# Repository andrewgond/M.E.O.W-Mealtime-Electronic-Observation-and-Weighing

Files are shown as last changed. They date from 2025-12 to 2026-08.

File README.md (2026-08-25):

---

# M.E.O.W. — Mealtime Electronic Observation & Weighing (WIP)

**An Open-Source Smart Pet Feeder with Integrated Weight Tracking**
*Senior Design Capstone — Oregon State University*
*Andrew Gondoputro
*Ahmad Alajmi
*Craig Kelley

---

## Project Status: Work in Progress (WIP)

This repository documents the development of the **M.E.O.W. automated pet feeder**, a system that dispenses food and logs pet weight using load cells and RFID identification. The goal is to support long-term tracking of pet health trends such as obesity, malnutrition, or abnormal feeding behavior.

---

# Overview

The M.E.O.W. system is designed to:

* Run on standard wall power
* Measure pet weight within ±20 grams
* Dispense food within ±60 grams
* Log food and weight data within 10 seconds
* Store at least 10 days of logs
* Support up to 4 pets via RFID
* Allow user-configurable feeding parameters

Unlike typical auto-feeders, M.E.O.W. integrates *health-relevant data logging* for improved wellness monitoring.

---

# DEI Commitment

The project emphasizes accessibility, inclusion, and open-source availability.
The system aims to be easy to use for any pet owner, with a simple UI and customizable configuration.

---

# System Architecture

## Top-Level Summary

The system is divided into modular subsystems:

* Power Distribution
* Enclosure & Kinematics
* Sensors
* Code & Database Storage
* Microcontroller (ESP32)
* UI + Web App

---

# 🔌 Block Diagram (Placeholder)

```
[ Block Diagram Placeholder — MEOW System ]
```

```
[ System-Level Diagram Placeholder — Showing Subsystem Connections ]
```

---

# 🔧 Subsystem Descriptions

### 1. Power Distribution

Converts AC wall power into stable low-voltage DC rails for sensors, logic, and actuators.

### 2. Enclosure & Kinematics

Includes the physical enclosure, motors, dispensing components, and protective mechanical structures.

### 3. Sensors

* Load cells to capture weight
* RFID reader for pet identification

### 4. Code & Database

MicroSD-based data storage for logs, timestamps, food dispensing events, and per-pet data.

### 5. Microcontroller

ESP32 manages sensors, actuator control, data logging, and UI communication.

### 6. UI + Web App

Browser-based dashboard for monitoring weight trends, adjusting feeding schedules, and visualizing logs.

---

# Interface Definitions

| Interface | Description |
| --- | --- |
| AC_pwr_in | Wall power input |
| DC_pwr_in_5v | Regulated 5V power rail |
| env_weight | Load cell weight signal |
| env_rfid_dist | RFID read distance |
| if_user_commands_in | User command interface |
| motor_ctrl_out | Motor control signals |
| ui_disp_ui | Display output |
| db_data_out | Data sent from database |
| db_data_to_ui | Data sent from microcontroller to UI |

---

# Verification Framework

Each subsystem will include:

* Interface validation
* General validation
* Verification steps
* References
* Success criteria

Example tasks include:

* Maximum current draw calculations
* Logic level matching (ESP32 ↔ SD card)
* Regulator thermal margins
* Sensor precision/accuracy tests

---

# References

A `/docs/references.md` file will be added containing:

* Component datasheets
* Industry standards
* Research sources for pet feeding and behavior
* Market analysis references

---

# Future Work

### Technical Recommendations (WIP)

* Improve sensor calibration algorithms
* Add multi-pet discrimination logic
* Enhance UI accessibility
* Expand SD logging features
* Improve enclosure materials

### Teamwork/Communication Recommendations

* Better task delegation strategy
* Implement weekly fixed-scope sprints

---

# Project Roadmap

### Phase 1 — Hardware Bring-Up

* [ ] Power subsystem validation
* [ ] Load cell calibration
* [ ] Servo/stepper testing
* [ ] RFID module bring-up

### Phase 2 — Firmware

* [ ] Sensor polling loops
* [ ] SD logging system
* [ ] Motor control logic
* [ ] Error handling

### Phase 3 — UI + Data

* [ ] Web dashboard
* [ ] Trend graphs
* [ ] Pet profiles

### Phase 4 — Final Integration

* [ ] Full hardware + firmware integration
* [ ] Enclosure finalization
* [ ] Stress testing
* [ ] Final documentation

---

# Contact

Project Contributors:

* Ahmad Alajmi
* Andrew Gondoputro
* Craig Kelley

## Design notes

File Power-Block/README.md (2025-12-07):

#1.1. Power Block - Andrew Gondoputro

This block is located on the exterior input of the system, accepting standard U.S. wall power and converting it into a regulated low-voltage DC bus at several predetermined voltages that all other M.E.O.W. subsystems can utilize. Every other block in the system depends on this stable power for its parts to function and is in charge of isolation, overcurrent protection, and providing enough power for the other components in the system.

#1.1.1. Description

The Power Distribution Block takes the AC_pwr_in interface with the US Standard 120 VAC, 60 Hz from a U.S. wall outlet. This allows us to plug into a wall and have a consistent power source, unlike a battery. Internally, the block then takes this AC wall power and turns it into a 12V rail, for higher voltage operations on the system like the kinematics of moving the stepper motors. It then uses that 12V rail to step down into both a 5V rail and a 3.3V rail, used for lower voltage components like the microcontroller, stepper drivers and sensors.

#1.1.2. Design

The design of the power station first starts with connecting to a wall outlet. Standard NEMA US Connectors consist of two pinned enclosures. We decided to have the cleanest AC->DC conversion to use a purchasable wall mount 12V 2A adapter with a barrel jack connector [10]. This also allows the cable of our overall system to be modular in which you can disconnect from the system and also easily replace.

Starting our circuit, we designed a barrel jack connector as an input for just a power and gnd, making sure that the footprint was right on the schematic. From the power pin A we put a Schmitt trigger diode so we would not get any accidental reverse current. The next node from the diode would just be used as the 12 V rail for the system since it was already cleaned by the adapter.

We decided to use two-buck conversions for the least amount of heat problems. We went with the LM2596S because of its easy accessibility of purchasing and consistent documentation and usages. The system then uses a 470uF and 1uF capacitor to deal with any low/high frequency noise. Our system uses two LM2596S taking the 12V input, with one LM2596S downstepping to 5V and the other downstepping to 3.3V. Following the example of [3, pg 1] we looked for capacitors and inductors and the wiring of the buck converters. Tables 9.1 and 9.3 [3, pg 21] showed us which inductors and capacitors to use. Which can be seen in our schematic [Figure 3.1.1]. The outputs of the buck converters gave us our rails we would be using.

Moving onto our PCB we that we decided that our project would later become open source, we tried to use a lot of through-hole components for easier assembly. We spent a long time looking for footprints and then making 1.5mm traces for high-power components. The pcb layout ended up being about the size of a credit card and can be seen in Figure 3.1.2. We then used screw terminals for the outputs of the rails for testing purposes when creating the PCB.

#Design Artifacts

Figure 3.1.1 KiCAD Schematic
Figure 3.1.2 KiCAD PCB Trace Schematic
Figure 3.1.2 KiCAD PCB 3D Model

#1.1.3. General Validation

It uses an AC to DC 12V power adapter to get the first regulated rail. It then uses a DC Voltage regulator to convert that 12V DC to a single 5 V DC regulated output that is used by the other blocks. Internally, this 5V is then fed into another voltage regulator to get a single 3.3 V DC regulated output for a microcontroller. This design aligns with the top-level system plan, which calls out a dedicated power block alongside enclosure/kinematics, sensors, microcontroller, code/database, and UI.

#1.1.4. Interface Validation

Interface property
Be sure to use the naming convention “from_to_type” here.
Why is this interface property this value?
How do you know your design details will meet or exceed this property? Cite your sources in IEEE.

**Interface 1: ext_power_acpwr**
| Interface property | Why is this interface property this value? | How do you know your design details will meet or exceed this property? |
| --- | --- | --- |
| **V_rms = 120 VAC @ 60 Hz (wall_pwr_pwr_ac)** | Section 1 and 2 say “The system will use standard US wall.” U.S. residential mains are 120 VAC nominal at 60 Hz. | The selected AC-DC module is rated for 90–132 VAC input at 47–63 Hz, so 120 VAC/60 Hz is inside range. [10] |
| **I_in_max ≤ 0.5 A (wall_pwr_pwr_ac)** | A 15 W / 5 V / 3 A supply at 120 VAC draws ~0.17 A even at poor PF. | Adapter rating guarantees operation below this current. [10] |
| **Connector = 2-pin shielded / enclosure mounted** | Since we take wall power, this is the easiest AC→DC form factor. | Using an IEC/2-pin inlet with strain relief meets electrical and mechanical requirements; it is also the purchased part. |
| **Barrel Connector Between PCB and Outlet** | Typical devices use a separate connector so the cord is removable. | 2.1 mm male/female barrel jacks are used. [10] |

**Interface 2. power_enc_dcpwr12v**
| Interface property | Why is this interface property this value? | How do you know your design meets this property? |
| --- | --- | --- |
| **V_min = 11.1 V (pwr_all_dcpwr)** | 12 V ±7.5% allows the buck converter and stepper motors to operate correctly. | Stepper motor is rated 8–35 V, well within range. [7] |
| **V_max = 12.9 V (pwr_all_dcpwr)** | Same tolerance requirement as above. | Stepper motor and converters operate fully across this range. [7] |
| **I_nom = 250 mA** | Expected slow-movement draw of the motor. | LM2596S converter maintains regulation at no load and normal load. [3] |
| **I_peak = 300 mA** | Ensures startup + acceleration overhead is supported. | Stepper motors typically require ≤ 300 mA under these operating conditions. [7] |

**Interface 3. dc_pwr_out_5v**

| Interface property | Why is this interface property this value? | How do you know your design meets/exceeds it? |
| --- | --- | --- |
| **V_min = 4.625 V** | 5 V −7.5% is USB and logic lower tolerance limit. | LM2596S guarantees ±10% output; verified by open-circuit tests. [3] |
| **V_max = 5.375 V** | 5 V +7.5% keeps downstream devices safe. | LM2596S ±5% accuracy meets this requirement. |
| **I_nominal = 100 mA** | Matches typical load cells and sensor current requirements. | ESP32 quiescent current = 5 mA; total expected load = 105 mA < nominal limit. [2][6] |
| **I_peak = 300 mA** | Supports transient demands. | Load remains below converter limit; ESP32 remains far under this threshold. |

Interface 4. dc_pwr_out_3.3v
| Interface property | Why is this interface property this value? | How do you know your design meets/exceeds it? |
| --- | --- | --- |
| **V_min = 3.0525 V** | 3.3 V −7.5% meets logic tolerance for ESP32/sensors. | LM2596S regulation ensures output stays above this even under load. |
| **V_max = 3.5475 V** | 3.3 V +7.5% stays within max voltage for logic chips. | Verified by open-circuit measurement ≤ 3.465 V. [3] |
| **I_nominal = 100 mA ± 25 mA** | Normal operating range for microcontroller + peripherals. | ESP32 quiescent is 5 mA; typical load ≤ 105 mA. |
| **I_peak = 300 mA** | Allows for transient inrush conditions. | Remains well below LM2596S converter limits. |

#1.1.5. Verification Process
Interface 1: ext_power_acpwr

Barrel Jack Connector and 2-pin shielded connector

Connect the cable to the system’s PCB barrel jack connector

Plug the system’s wall connector into the wall
VRMS (NEMA Standard) and Iinmax (Wall Adapter)

Use a multimeter on the rails to check the voltage of each rail receiving their expected values

Fully verify the interfaces 2-4 validation’s to ensure its working'

Interface 2: power_enc_dcpwr12v

11.1V < Vout < 12.9V and Imin= 0 (Verifying when motor off)

Disconnect any loads on the 12V rail

While the system is connected to wall power, use a multimeter to verify that the values are within the range

11.4V < Vout < 12.6V when Imax= 250 mA (Verifying when motor on)
3. Have the system disconnected from the wall
4. Put the electronic load on the 12V rail with power and gnd properly wired
a. Set the load to I = 0.3 and then turn it on
b. Put a resistor value of 22 ohms on the 5V Rail (Simulating I = 227mA)
c. resistor value of 22 ohms on the 3V Rail (Simulating I = 150mA)
5. Plug the system into the wall
6. Check the electronic load to see the actual current and the voltage across the node to verify its within the values

11.4V < Vout < 12.6V when Imax = 300 mA (Verifying under max load range)

Unplug the system

Change electronic load to I=0.3

Plug the system back into the wall

Check the electronic load to see the actual current and the voltage across the node to verify its within the values

Interface 3: power_sensors_dcpwr5v

4.625 V < Vout < 5.375 V
5. Disconnect any loads on the 5V rail
6. While the system is connected to wall power, use a multimeter to verify that the values are within the range

4.625 V < Vout < 5.375 V when Inom = 200 mA (Verifying under nominal load range)
7. Have the system disconnected from the wall
8. Put the electronic load on the 12V rail with power and gnd properly wired
a. Set the load to I = 0.1 and then turn it on
b. Put a resistor value of 47 ohms on the 12V Rail (Simulating I = 255mA)
c. resistor value of 22 ohms on the 3V Rail (Simulating I = 150mA)
9. Plug the system into the wall
10. Check the electronic load to see the actual current and the voltage across the node to verify its within the values

4.625 V < Vout < 5.375 V when Imax = 300 mA (Verifying under max load range)
11. Unplug the system
12. Change electronic load to I=0.3
13. Plug the system back into the wall
14. Check the electronic load to see the actual current and the voltage across the node to verify its within the values

Interface 4: power_enc_dcpwr3.3v

3.05 V < Vout < 3.55 V (Verifying when system idle)

Disconnect any loads on the 12V rail

While the system is connected to wall power, use a multimeter to verify that the values are within the range

3.05 V < Vout < 3.55 V when Inom = 200 mA (Verifying under nominal load range)
3. Have the system disconnected from the wall
4. Put the electronic load on the 12V rail with power and gnd properly wired
a. Set the load to I = 0.1 and then turn it on
b. Put a resistor value of 47 ohms on the 12V Rail (Simulating I = 255mA)
c. resistor value of 22 ohms on the 5V Rail (Simulating I = 227mA)
5. Plug the system into the wall
6. Check the electronic load to see the actual current and the voltage across the node to verify its within the values

3.05 V < Vout < 3.55 V when Imax = 300 mA (Verifying under max load range)
7. Unplug the system
8. Change electronic load to I=0.3
9. Plug the system back into the wall
10. Check the electronic load to see the actual current and the voltage across the node to verify its within the values

1.1.6. References

(All references preserved exactly from the PDF)

[1] Americord Custom Power Cords, “NEMA Chart: Know Your Plug And Receptacle,” Americord Blog, Jul. 24, 2021.
[2] ON Semiconductor, “NCP1117/D: 1.0 A Low-Dropout Positive Fixed and Adjustable Voltage Regulators.”
[3] Texas Instruments / LM2596S Evaluation Module, “LM2596S EV Board Datasheet,” Digi-Key, 2020.
[4] Cliff Electronic Components Ltd., “Model No. DC-10A / DC-10B – Part No. FC68148.”
[5] Espressif Systems, “ESP32-WROOM-32 Datasheet.”
[6] SparkFun Electronics, “ESP32 Datasheet (Alternate Copy).”
[7] Allegro MicroSystems, “A4988: Microstepping Motor Driver with Translator.”
[8] Rubycon Corp., “YXJ Series Aluminum Electrolytic Capacitors.”
[9] Rubycon Corp., “ZLH Series Aluminum Electrolytic Capacitors.”
[10] Yageo Group, “12V 2A Power Supply.”
[11] Vishay Semiconductors, “1N5820 Schottky Barrier Rectifier.”
[12] Würth Elektronik, “744731680 – WE-PD Series Shielded Power Inductor.”
[13] Würth Elektronik, “7447471470 – WE-HCI Series High-Current Inductor.”
[14] Texas Instruments, “LM2596: SIMPLE SWITCHER® 150-kHz 3-A Step-Down Voltage Regulator.”

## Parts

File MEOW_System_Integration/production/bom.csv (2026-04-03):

Designator | Footprint | Quantity | Value | LCSC Part #
- 12V +, - 3.3V +, - 5V + | TerminalBlock_TE_282834-2_1x02_P2.54mm_Horizontal | 3 | Terminal Out (Screw)
A1 | Pololu_Breakout-16_15.2x20.3mm | 1 | A4988
C1 | CP_Elec_8x10 | 1 | 470 uF
C2 | 0603 | 1 | 1uF
C3, C4 | CP_Elec_6.3x7.7 | 2 | 220 uF
C5 | 0603 | 1 | 0.1uF
D1, D2, D3 | D_SMA | 3 | 1N5820
J1, J11 | PinHeader_1x04_P2.54mm_Vertical | 2 | Conn_01x04_Pin
J10, J8 | PinHeader_1x19_P2.54mm_Vertical | 2 | Conn_01x19_Pin
J12, J15 | PinSocket_1x02_P2.54mm_Vertical | 2 | Conn_01x02_Pin
J9 | PinSocket_1x04_P2.54mm_Vertical | 1 | Conn_01x04_Pin
JP1 | JST_EH_B2B-EH-A_1x02_P2.50mm_Vertical | 1 | Power Connector
JP2 | JST_EH_B2B-EH-A_1x02_P2.50mm_Vertical | 1 | Power Switch Connector
L1 | L_12x12mm_H4.5mm | 1 | 68 uH
L2 | L_12x12mm_H4.5mm | 1 | 47uH
MCU1 | ESP32_38pin | 1 | ~
R1, R2, R3, R4, R5 | 0603 | 5 | 10kohm
RDM1 | RDM6300 | 1 | RDM6300
S1, S2 | SPARKFUN_SEN-13879 | 2 | SEN-13879
SD1 | MEM20900014500A | 1 | MEM2090-00-145-00-A
U1 | TO-263-5_TabPin3 | 1 | LM2596S-5
U2 | TO-263-5_TabPin3 | 1 | LM2596S-3.3

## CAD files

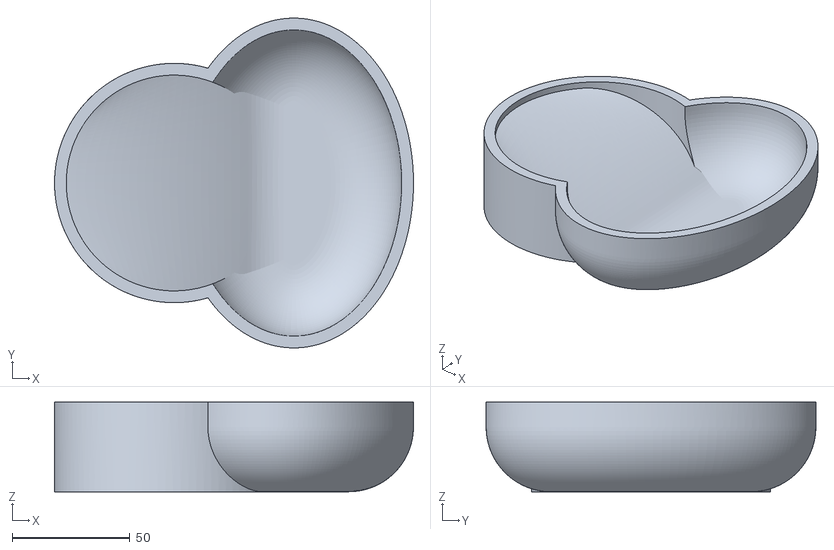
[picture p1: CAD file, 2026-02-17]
Enclosure-Kinematics-Block/3D-Models/EncBowlV1.stl
152.4 x 140.0 x 38.0

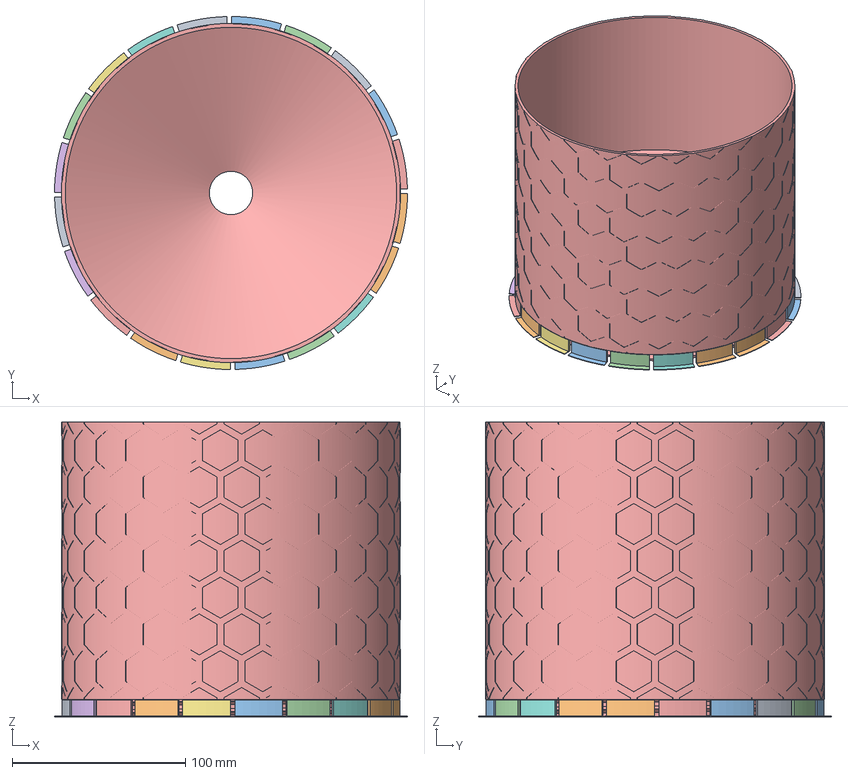
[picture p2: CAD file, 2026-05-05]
EnclosureV2_Print_Models/Top.3mf
203.6 x 203.6 x 170.0 mm

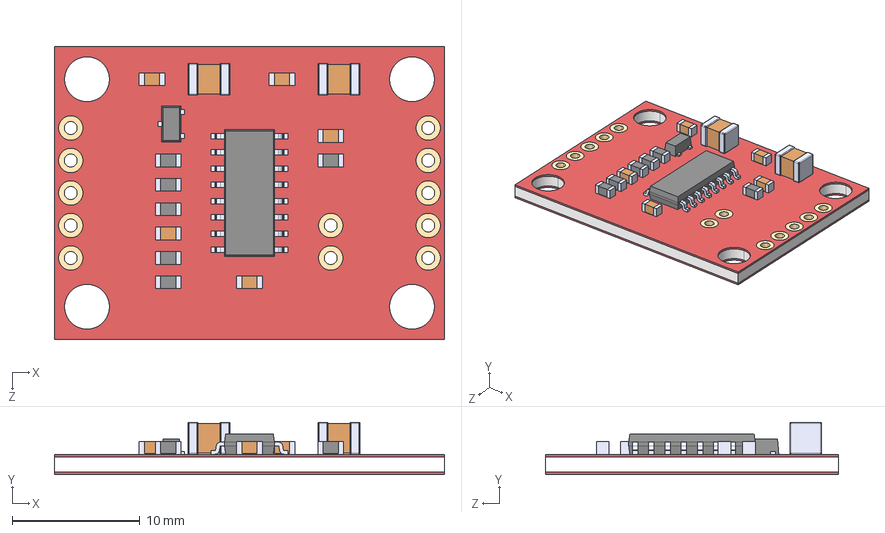
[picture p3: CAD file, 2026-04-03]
Extra Kicad Libraries/KiCAD_Footprints/SEN-13879.step
30.5 x 4.10 x 22.9 mm

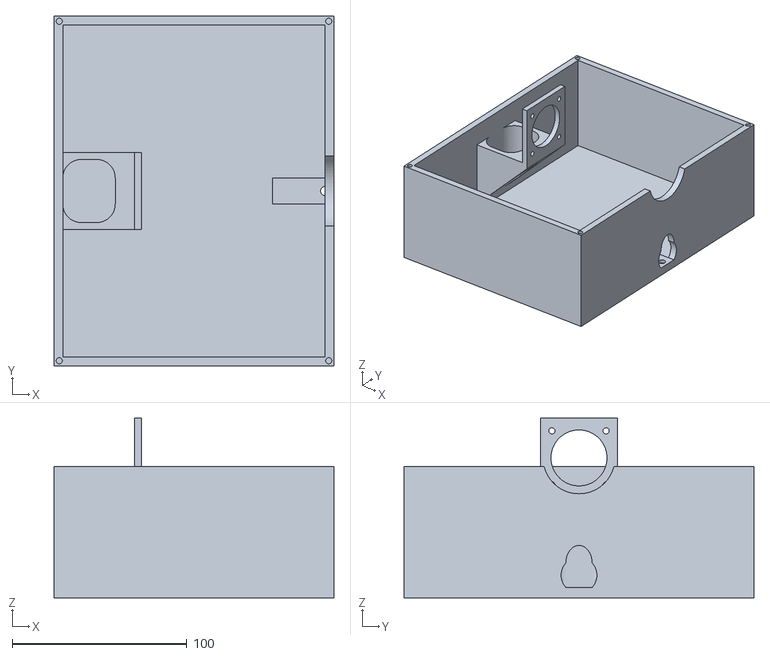
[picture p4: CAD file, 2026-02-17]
Enclosure-Kinematics-Block/3D-Models/EncBotV1.stl
160.0 x 200.0 x 102.8

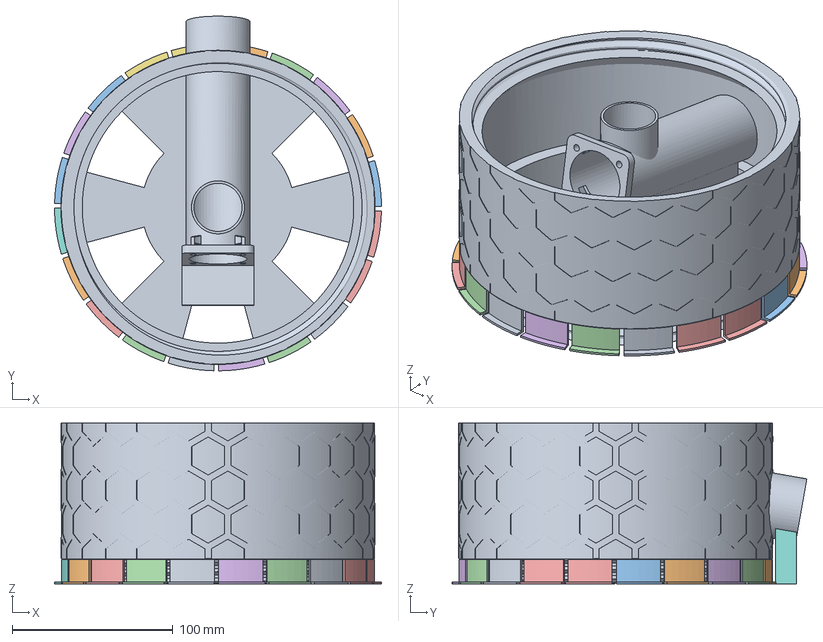
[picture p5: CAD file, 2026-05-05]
EnclosureV2_Print_Models/mid.3mf
203.6 x 220.8 x 100.0 mm

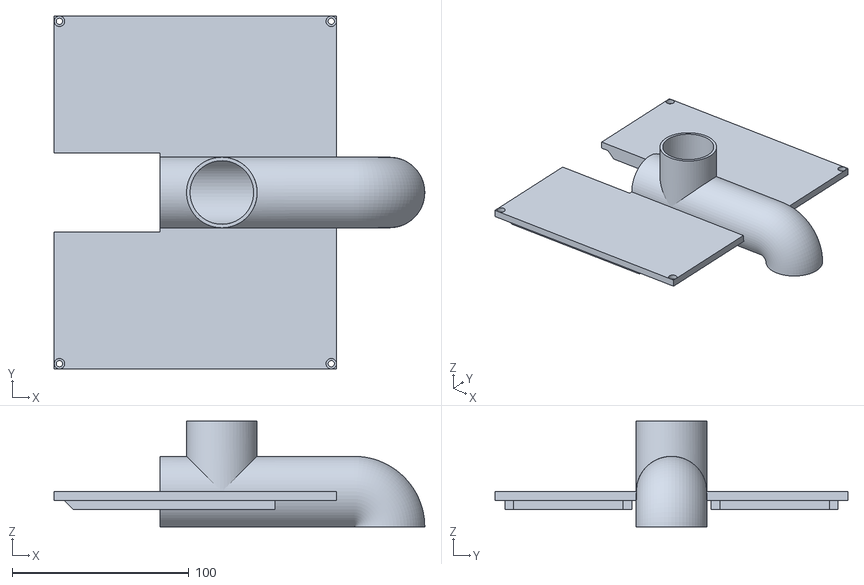
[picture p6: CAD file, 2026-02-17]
Enclosure-Kinematics-Block/3D-Models/EncTopV1.stl
210.0 x 200.0 x 60.0

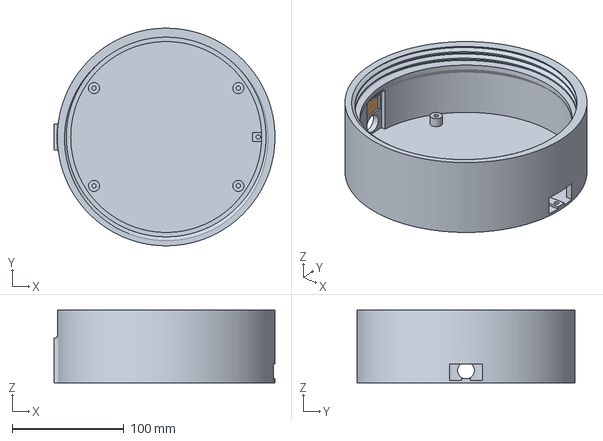
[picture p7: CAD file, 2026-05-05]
EnclosureV2_Print_Models/bottom.3mf
198.0 x 194.9 x 65.0 mm

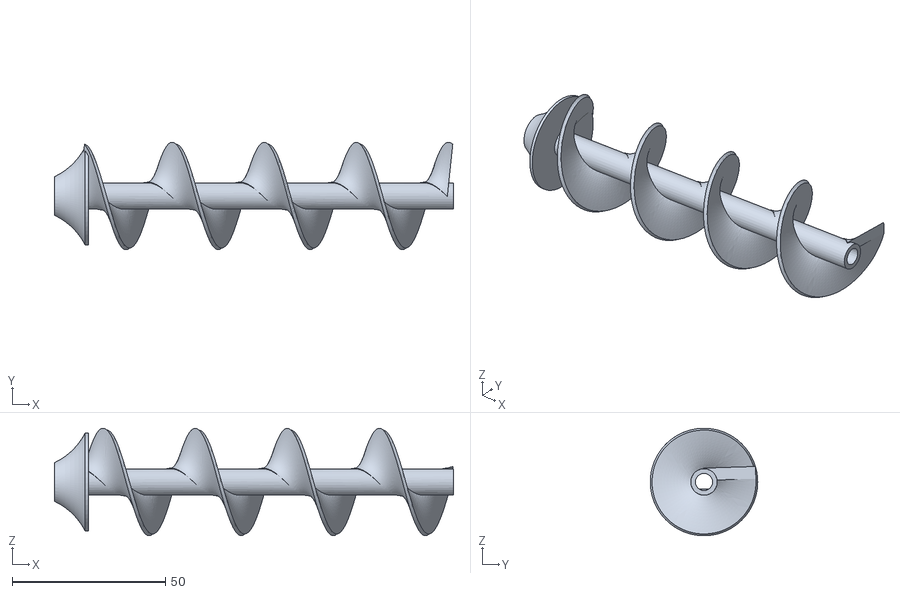
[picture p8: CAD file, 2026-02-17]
Enclosure-Kinematics-Block/3D-Models/EncAugerV1.stl
130.0 x 35.0 x 35.0

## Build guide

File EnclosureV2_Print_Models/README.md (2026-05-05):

https://www.thingiverse.com/Andrewsarchus/designs?

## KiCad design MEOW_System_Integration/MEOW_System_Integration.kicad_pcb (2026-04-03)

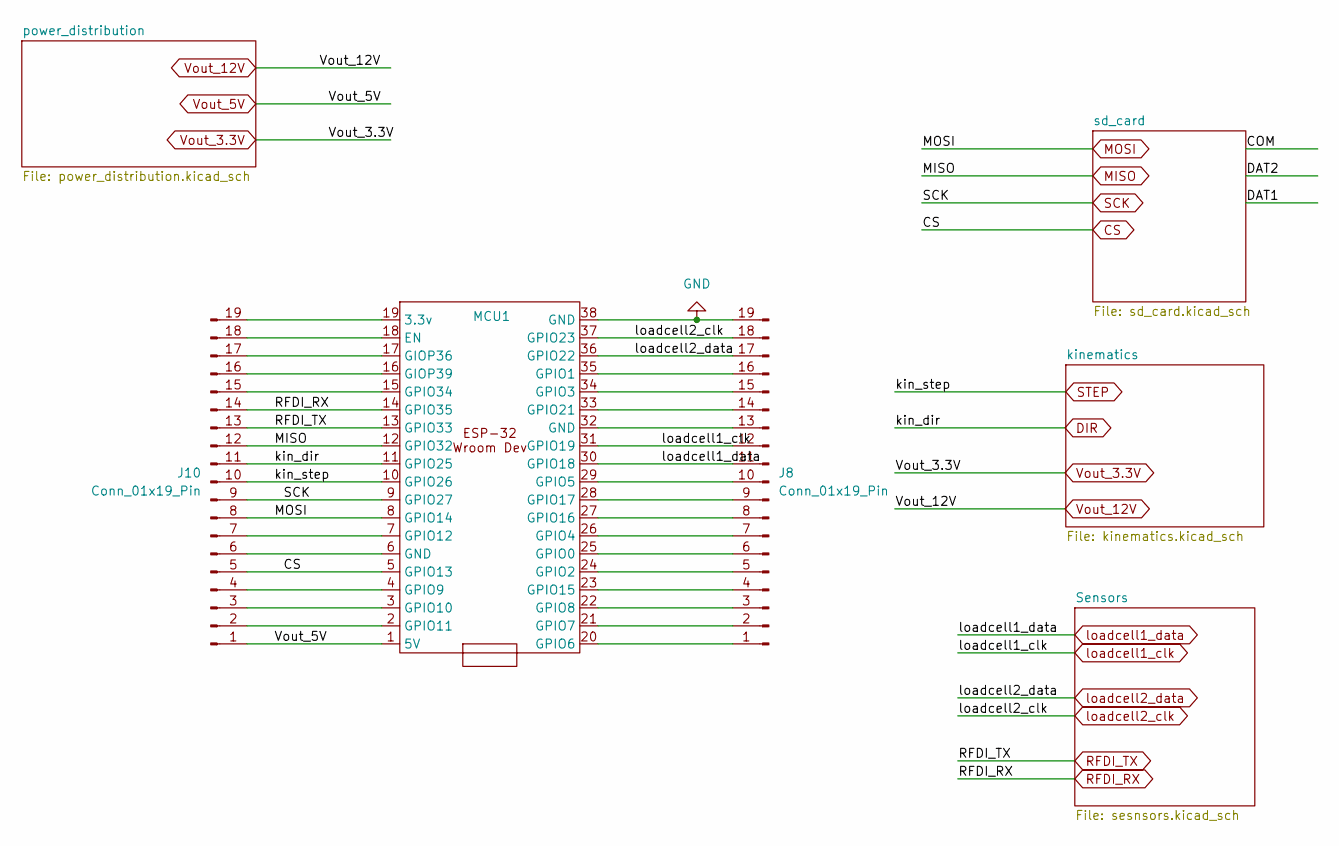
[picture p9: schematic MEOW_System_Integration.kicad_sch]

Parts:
J8, J10: Conn_01x19_Pin; PinHeader_1x19_P2.54mm_Vertical
MCU1: ESP32_38pin

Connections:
CS: J10.5, MCU1.5 (GPIO13); also elsewhere on the board
DIR: J10.11, MCU1.11 (GPIO25); also elsewhere on the board
GND: J8.19, MCU1.38 (GND); also elsewhere on the board
MISO: J10.12, MCU1.12 (GPIO32); also elsewhere on the board
MOSI: J10.8, MCU1.8 (GPIO14); also elsewhere on the board
unnamed: J8.1, MCU1.20 (GPIO6)
unnamed: J8.2, MCU1.21 (GPIO7)
unnamed: J8.3, MCU1.22 (GPIO8)
unnamed: J8.4, MCU1.23 (GPIO15)
unnamed: J8.5, MCU1.24 (GPIO2)
unnamed: J8.6, MCU1.25 (GPIO0)
unnamed: J8.7, MCU1.26 (GPIO4)
unnamed: J8.8, MCU1.27 (GPIO16)
unnamed: J8.9, MCU1.28 (GPIO17)
unnamed: J8.10, MCU1.29 (GPIO5)
unnamed: J8.13, MCU1.32 (GND)
unnamed: J8.14, MCU1.33 (GPIO21)
unnamed: J8.15, MCU1.34 (GPIO3)
unnamed: J8.16, MCU1.35 (GPIO1)
unnamed: J10.2, MCU1.2 (GPIO11)
unnamed: J10.3, MCU1.3 (GPIO10)
unnamed: J10.4, MCU1.4 (GPIO9)
unnamed: J10.6, MCU1.6 (GND)
unnamed: J10.7, MCU1.7 (GPIO12)
unnamed: J10.15, MCU1.15 (GPIO34)
unnamed: J10.16, MCU1.16 (GIOP39)
unnamed: J10.17, MCU1.17 (GIOP36)
unnamed: J10.18, MCU1.18 (EN)
unnamed: J10.19, MCU1.19 (3.3v)
RFDI_RX: J10.14, MCU1.14 (GPIO35); also elsewhere on the board
RFDI_TX: J10.13, MCU1.13 (GPIO33); also elsewhere on the board
SCK: J10.9, MCU1.9 (GPIO27); also elsewhere on the board
STEP: J10.10, MCU1.10 (GPIO26); also elsewhere on the board
Vout_5V: J10.1, MCU1.1 (5V); also elsewhere on the board
loadcell1_clk: J8.12, MCU1.31 (GPIO19); also elsewhere on the board
loadcell1_data: J8.11, MCU1.30 (GPIO18); also elsewhere on the board
loadcell2_clk: J8.18, MCU1.37 (GPIO23); also elsewhere on the board
loadcell2_data: J8.17, MCU1.36 (GPIO22); also elsewhere on the board

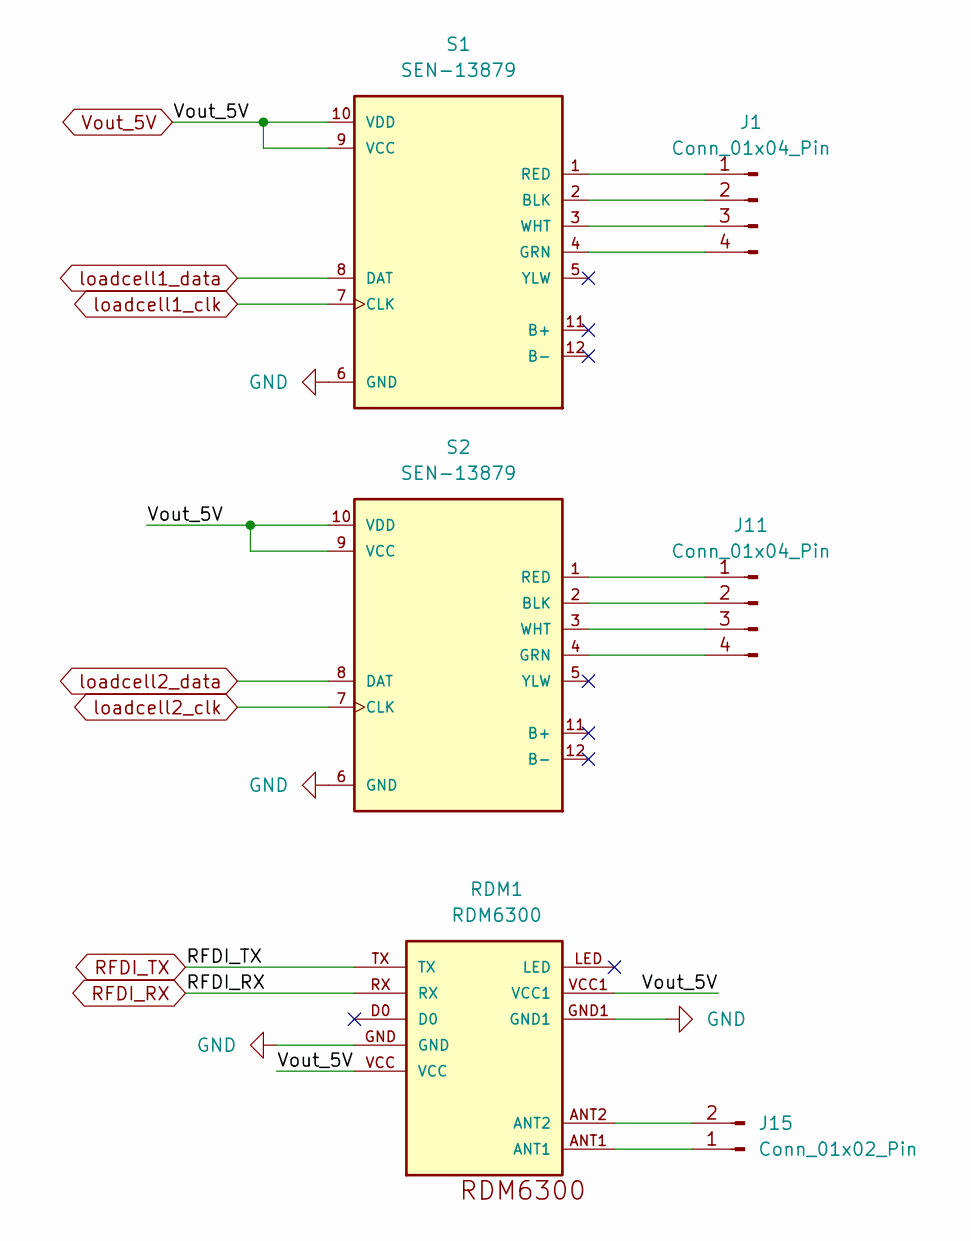
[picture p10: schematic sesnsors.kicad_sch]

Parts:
J1, J11: Conn_01x04_Pin; PinHeader_1x04_P2.54mm_Vertical
J15: Conn_01x02_Pin; PinSocket_1x02_P2.54mm_Vertical
RDM1: RDM6300
S1, S2: SEN-13879; SPARKFUN_SEN-13879

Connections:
GND: RDM1.GND, RDM1.GND1, S1.6 (GND), S2.6 (GND); also elsewhere on the board
unnamed: J1.1, S1.1 (RED)
unnamed: J1.2, S1.2 (BLK)
unnamed: J1.3, S1.3 (WHT)
unnamed: J1.4, S1.4 (GRN)
unnamed: J11.1, S2.1 (RED)
unnamed: J11.2, S2.2 (BLK)
unnamed: J11.3, S2.3 (WHT)
unnamed: J11.4, S2.4 (GRN)
unnamed: J15.1, RDM1.ANT1
unnamed: J15.2, RDM1.ANT2
RFDI_RX: RDM1.RX; also elsewhere on the board
RFDI_TX: RDM1.TX; also elsewhere on the board
Vout_5V: RDM1.VCC, RDM1.VCC1, S1.9 (VCC), S1.10 (VDD), S2.9 (VCC), S2.10 (VDD); also elsewhere on the board
loadcell1_clk: S1.7 (CLK); also elsewhere on the board
loadcell1_data: S1.8 (DAT); also elsewhere on the board
loadcell2_clk: S2.7 (CLK); also elsewhere on the board
loadcell2_data: S2.8 (DAT); also elsewhere on the board

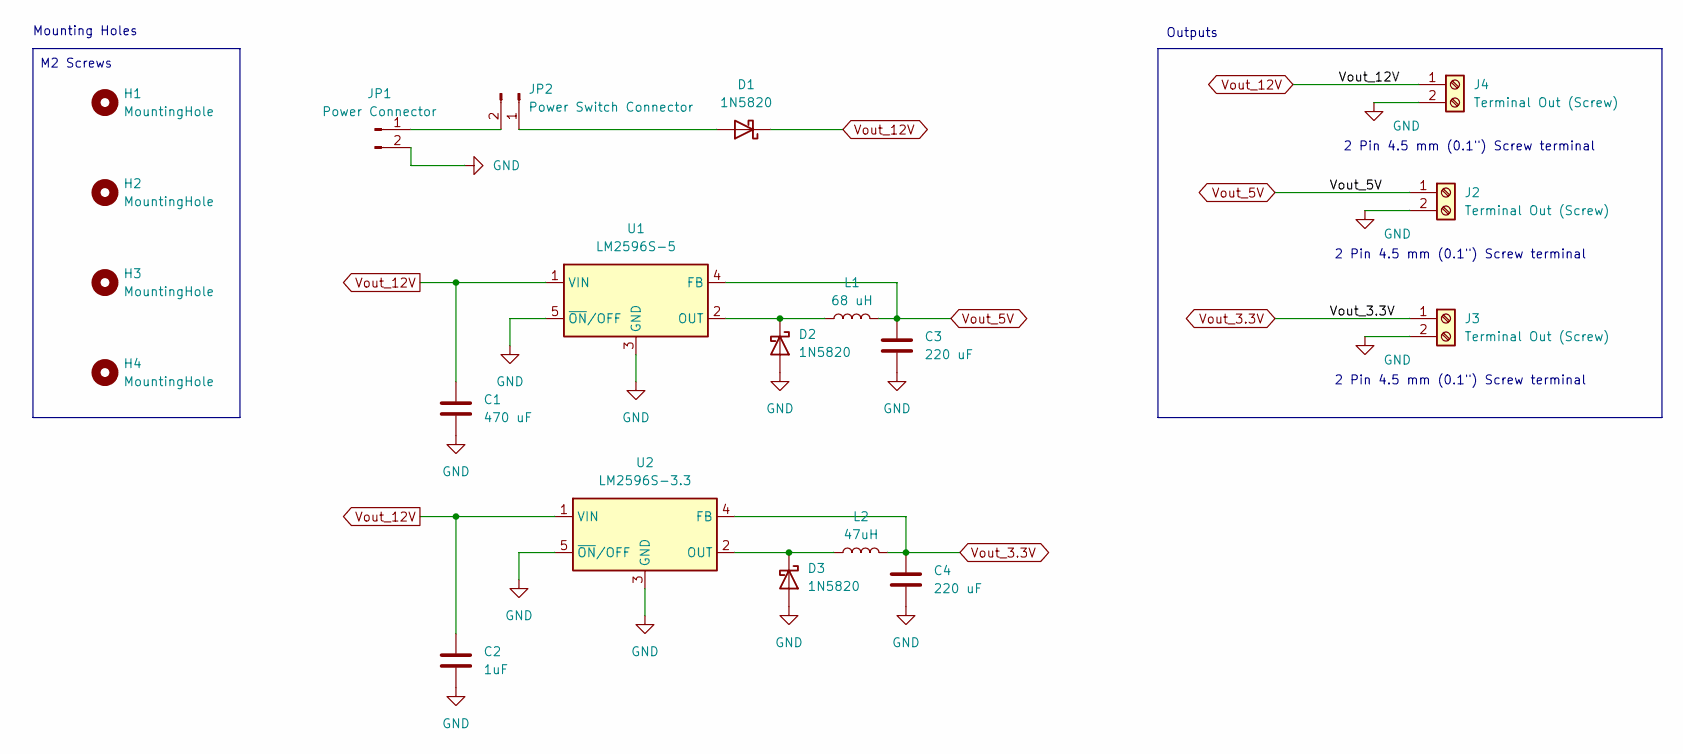
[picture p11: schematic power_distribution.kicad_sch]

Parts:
C1: 470 uF; CP_Elec_8x10
C2: 1uF; C_0603_1608Metric
C3, C4: 220 uF; CP_Elec_6.3x7.7
D1, D2, D3: 1N5820; D_SMA
H1, H2, H3, H4: MountingHole; MountingHole_3mm
J2, J3, J4: Terminal Out (Screw); TerminalBlock_TE_282834-2_1x02_P2.54mm_Horizontal
JP1: Power Connector; JST_EH_B2B-EH-A_1x02_P2.50mm_Vertical
JP2: Power Switch Connector; JST_EH_B2B-EH-A_1x02_P2.50mm_Vertical
L1: 68 uH; L_12x12mm_H4.5mm
L2: 47uH; L_12x12mm_H4.5mm
U1: LM2596S-5; TO-263-5_TabPin3
U2: LM2596S-3.3; TO-263-5_TabPin3

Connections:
GND: C1.2, C2.2, C3.2, C4.2, D2.2 (A), D3.2 (A), JP1.2, U1.3 (GND), U1.5 (~ON/OFF), U2.3 (GND), U2.5 (~ON/OFF); also elsewhere on the board
unnamed: D1.2 (A), JP2.1
unnamed: D2.1 (K), L1.1, U1.2 (OUT)
unnamed: D3.1 (K), L2.1, U2.2 (OUT)
unnamed: JP1.1, JP2.2
Vout_3.3V: C4.1, L2.2, U2.4 (FB); also elsewhere on the board
Vout_5V: C3.1, L1.2, U1.4 (FB); also elsewhere on the board
Vout_12V: C1.1, C2.1, D1.1 (K), U1.1 (VIN), U2.1 (VIN); also elsewhere on the board

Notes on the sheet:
Outputs
2 Pin 4.5 mm (0.1") Screw terminal
Mounting Holes
M2 Screws

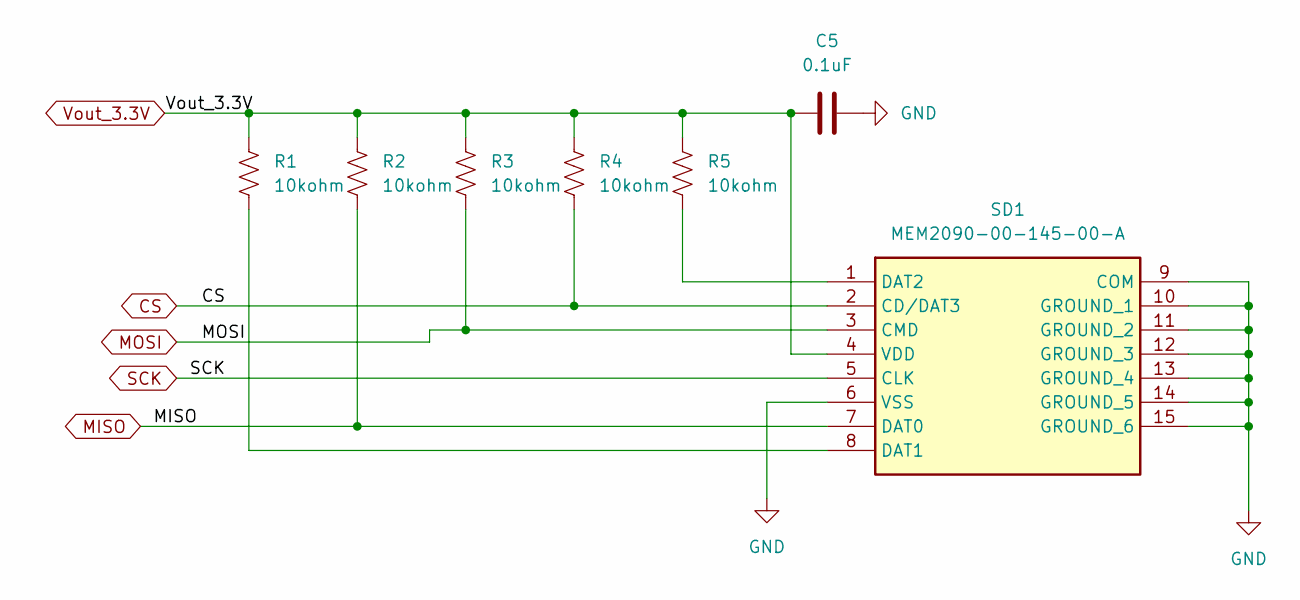
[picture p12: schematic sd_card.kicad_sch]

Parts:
C5: 0.1uF; C_0603_1608Metric
R1, R2, R3, R4, R5: 10kohm; R_0603_1608Metric_Pad0.98x0.95mm_HandSolder
SD1: MEM2090-00-145-00-A; MEM20900014500A; Mouser Part Number 640-MEM20900014500A

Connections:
CS: R4.2, SD1.2 (CD/DAT3); also elsewhere on the board
GND: C5.2, SD1.6 (VSS), SD1.9 (COM), SD1.10 (GROUND_1), SD1.11 (GROUND_2), SD1.12 (GROUND_3), SD1.13 (GROUND_4), SD1.14 (GROUND_5), SD1.15 (GROUND_6); also elsewhere on the board
MISO: R2.2, SD1.7 (DAT0); also elsewhere on the board
MOSI: R3.2, SD1.3 (CMD); also elsewhere on the board
unnamed: R1.2, SD1.8 (DAT1)
unnamed: R5.2, SD1.1 (DAT2)
SCK: SD1.5 (CLK); also elsewhere on the board
Vout_3.3V: C5.1, R1.1, R2.1, R3.1, R4.1, R5.1, SD1.4 (VDD); also elsewhere on the board

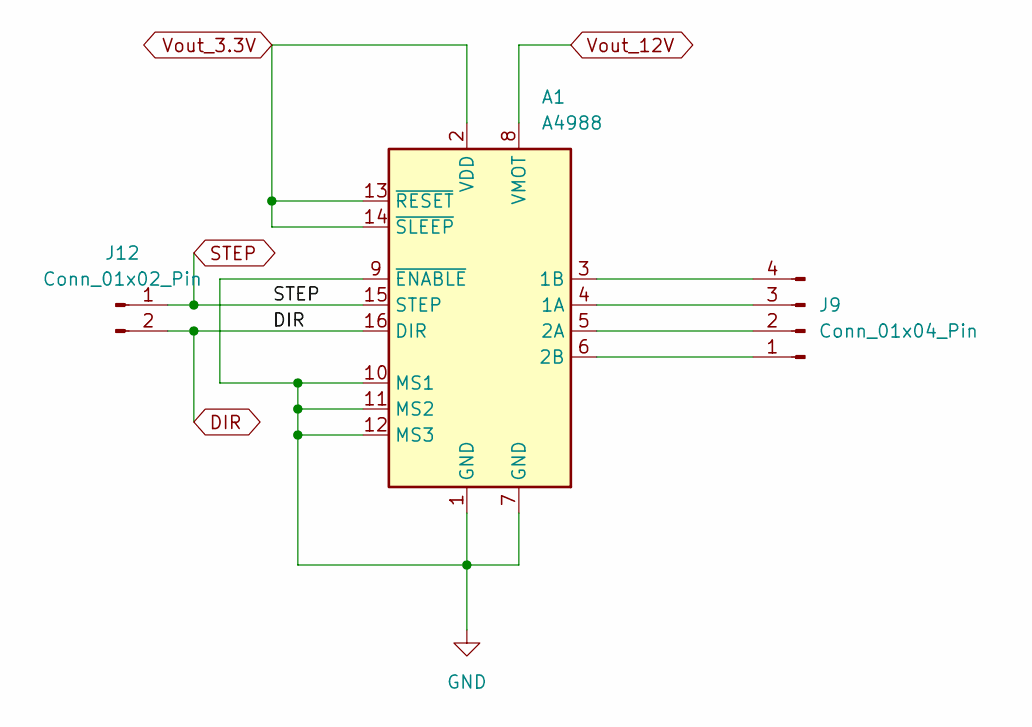
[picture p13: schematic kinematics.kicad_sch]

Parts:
A1: A4988; Pololu_Breakout-16_15.2x20.3mm
J9: Conn_01x04_Pin; PinSocket_1x04_P2.54mm_Vertical
J12: Conn_01x02_Pin; PinSocket_1x02_P2.54mm_Vertical

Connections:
DIR: A1.16 (DIR), J12.2; also elsewhere on the board
GND: A1.1 (GND), A1.7 (GND), A1.9 (~ENABLE), A1.10 (MS1), A1.11 (MS2), A1.12 (MS3); also elsewhere on the board
unnamed: A1.4 (1A), J9.3
unnamed: A1.3 (1B), J9.4
unnamed: A1.5 (2A), J9.2
unnamed: A1.6 (2B), J9.1
STEP: A1.15 (STEP), J12.1; also elsewhere on the board
Vout_3.3V: A1.2 (VDD), A1.13 (~RESET), A1.14 (~SLEEP); also elsewhere on the board
Vout_12V: A1.8 (VMOT); also elsewhere on the board

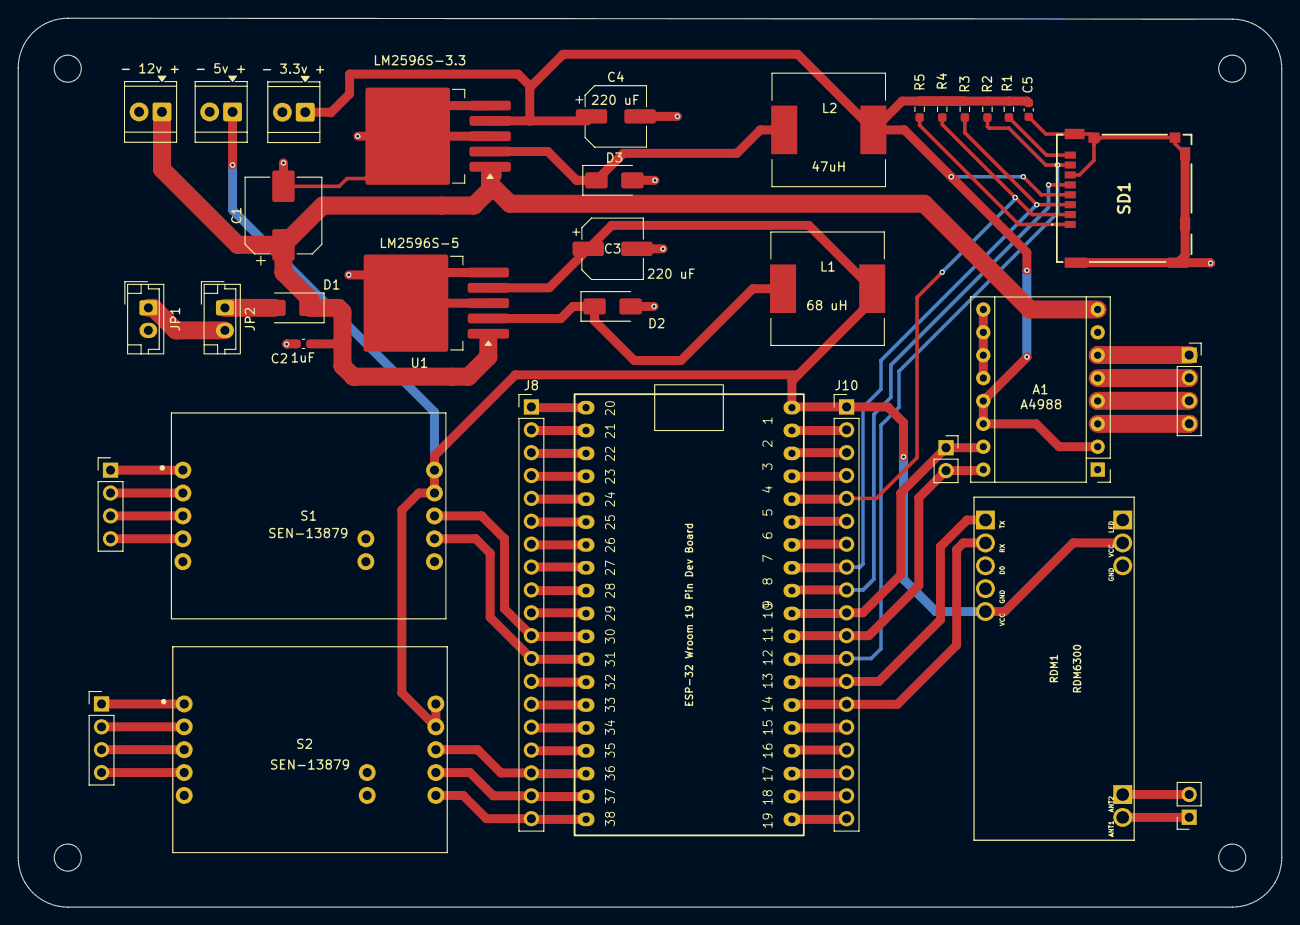
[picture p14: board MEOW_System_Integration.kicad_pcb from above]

Board: 2 copper layers, 140.3 x 98.7 mm, 39 parts (0 on the bottom side), 60 nets.

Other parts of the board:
- 3.3v +, - 5v +, - 12v +: Terminal Out (Screw); TerminalBlock_TE_282834-2_1x02_P2.54mm_Horizontal

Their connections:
GND: - 3.3v +.2, - 5v +.2, - 12v +.2; also elsewhere on the board
Vout_3.3V: - 3.3v +.1; also elsewhere on the board
Vout_5V: - 5v +.1; also elsewhere on the board
Vout_12V: - 12v +.1; also elsewhere on the board

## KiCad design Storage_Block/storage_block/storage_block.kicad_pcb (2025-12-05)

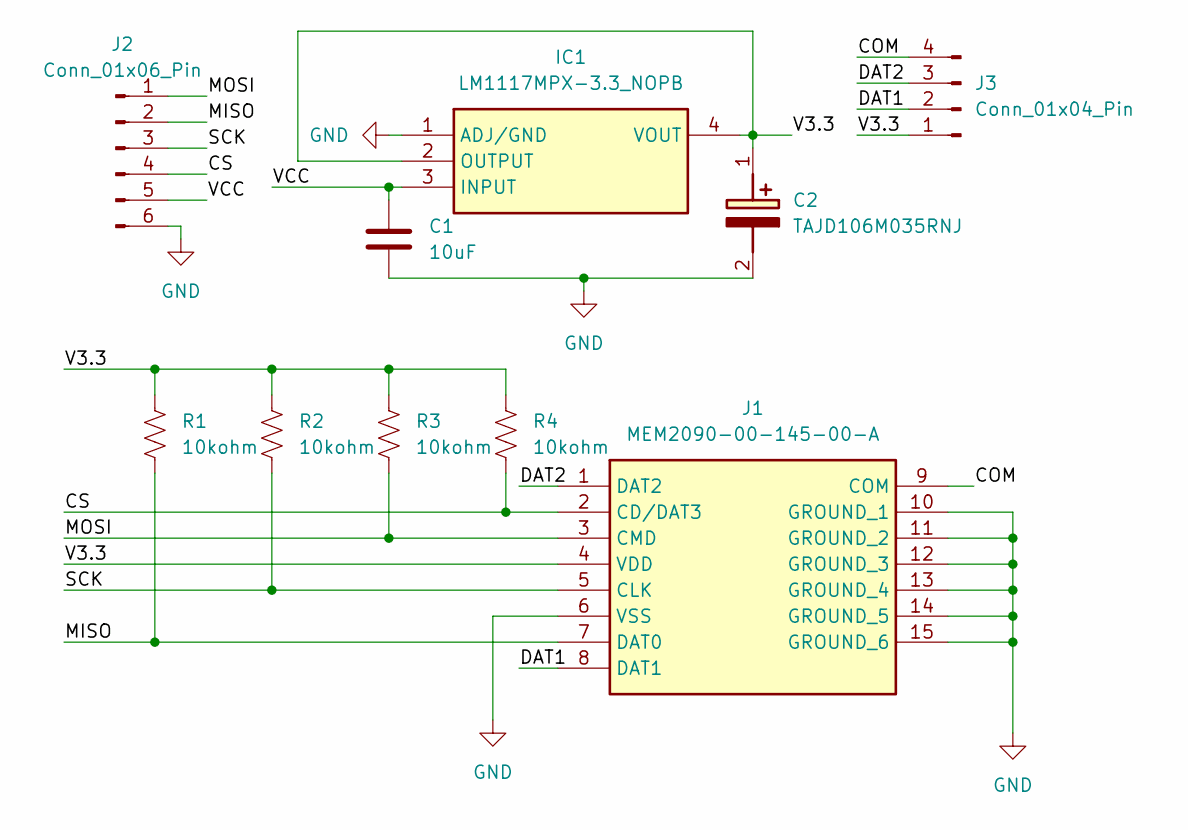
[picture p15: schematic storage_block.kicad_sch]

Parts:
C1: 10uF; C_1206_3216Metric_Pad1.33x1.80mm_HandSolder
C2: TAJD106M035RNJ; CAPPM7344X310N; Mouser Part Number 581-TAJD106M035R
IC1: LM1117MPX-3.3_NOPB; SOT230P700X180-4N; Mouser Part Number 926-LM1117MPX3.3NOPB
J1: MEM2090-00-145-00-A; MEM20900014500A; Mouser Part Number 640-MEM20900014500A
J2: Conn_01x06_Pin; PinHeader_1x06_P2.54mm_Vertical
J3: Conn_01x04_Pin; PinHeader_1x04_P2.54mm_Vertical
R1, R2, R3, R4: 10kohm; R_0603_1608Metric_Pad0.98x0.95mm_HandSolder

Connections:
/COM: J1.9 (COM), J3.4
/CS: J1.2 (CD/DAT3), J2.4, R4.2
/DAT1: J1.8 (DAT1), J3.2
/DAT2: J1.1 (DAT2), J3.3
/MISO: J1.7 (DAT0), J2.2, R1.2
/MOSI: J1.3 (CMD), J2.1, R3.2
/SCK: J1.5 (CLK), J2.3, R2.2
/V3.3: C2.1 (+), IC1.2 (OUTPUT), IC1.4 (VOUT), J1.4 (VDD), J3.1, R1.1, R2.1, R3.1, R4.1
/VCC: C1.2, IC1.3 (INPUT), J2.5
GND: C1.1, C2.2 (-), IC1.1 (ADJ/GND), J1.6 (VSS), J1.10 (GROUND_1), J1.11 (GROUND_2), J1.12 (GROUND_3), J1.13 (GROUND_4), J1.14 (GROUND_5), J1.15 (GROUND_6), J2.6

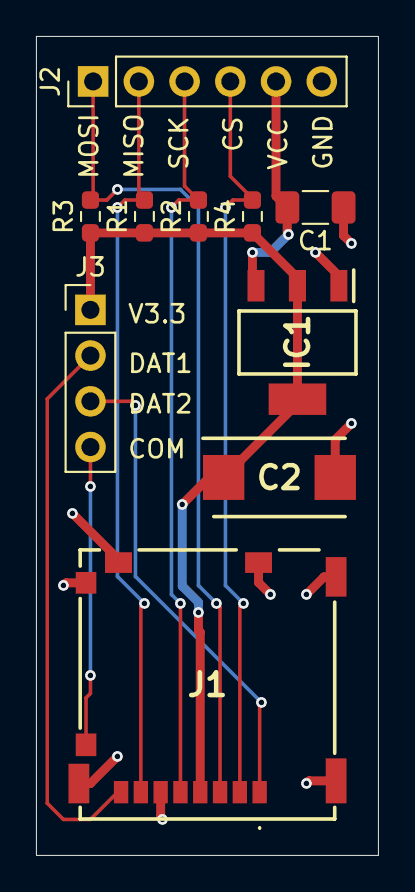
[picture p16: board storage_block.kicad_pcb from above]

Board: 2 copper layers, 19.0 x 45.5 mm, 10 parts (0 on the bottom side), 10 nets.

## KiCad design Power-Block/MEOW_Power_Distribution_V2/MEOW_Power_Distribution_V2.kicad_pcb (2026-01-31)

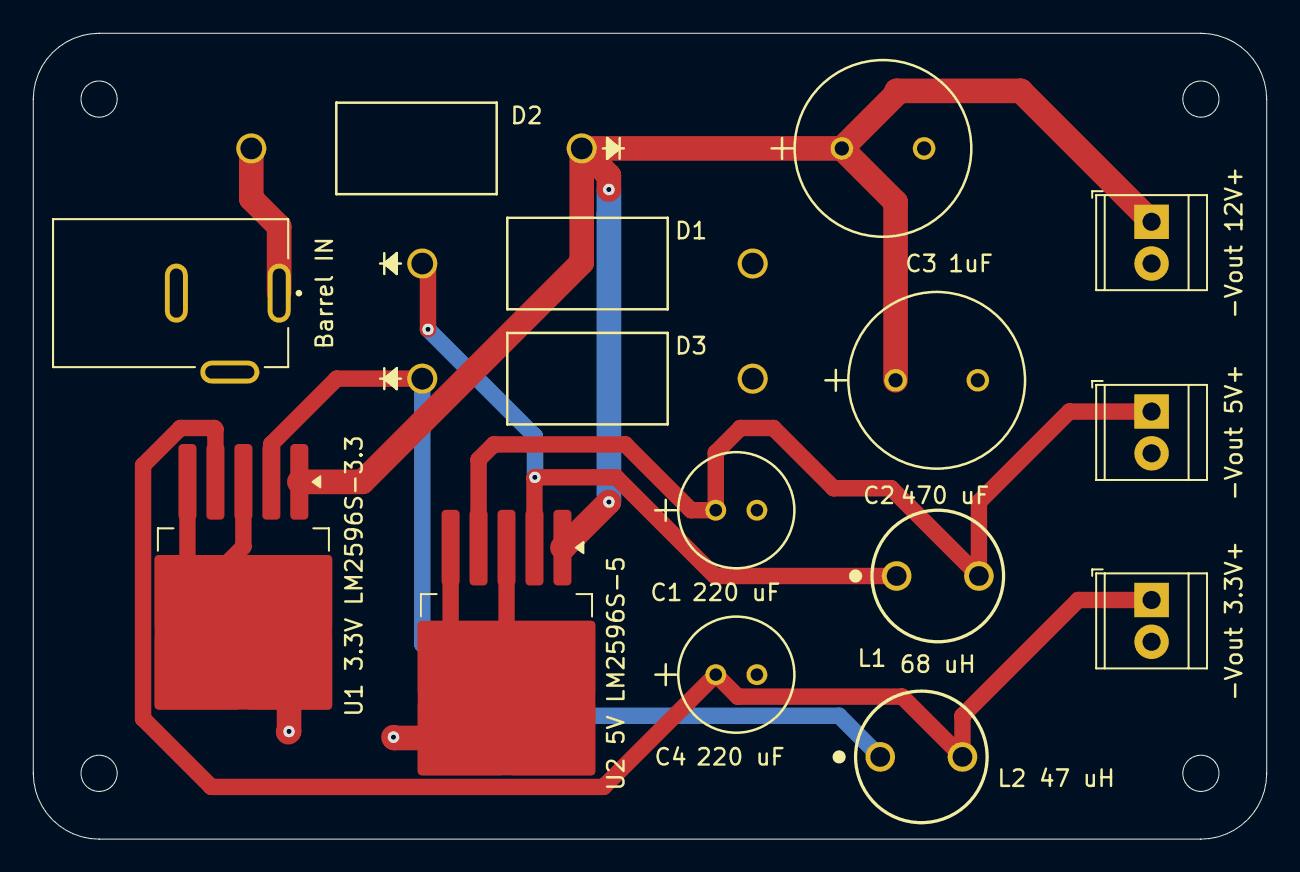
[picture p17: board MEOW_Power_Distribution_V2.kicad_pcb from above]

Board: 2 copper layers, 75.0 x 49.0 mm, 19 parts (0 on the bottom side), 7 nets.

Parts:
Barrel IN: 54-00166; TENSILITY_54-00166
C1, C4: 220 uF; CAP_YX_6P3X11_RUB
C2: 470 uF; CAP_YX_10X12P5_RUB
C3: 1uF; CAP_YX_10X12P5_RUB
D1, D2, D3: 1N5820; CR_0-E3&slash_54_VIS
H1, H2, H3, H4: MountingHole; MountingHole_2.2mm_M2
J3, J4, J6: Terminal Out (Screw); TerminalBlock_TE_282834-2_1x02_P2.54mm_Horizontal
L1: 68 uH; WE-TIS_8075
L2 47 uH: 47uH; WE-TIS_8075
U1 3.3V LM2596S-3.3: LM2596S-3.3; TO-263-5_TabPin3
U2 5V LM2596S-5: LM2596S-5; TO-263-5_TabPin3

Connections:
GND: Barrel IN.B, C1.2, C2.2, C3.2, C4.2, D1.2 (A), D3.2 (A), J3.2, J4.2, J6.2, U1 3.3V LM2596S-3.3.3 (GND), U1 3.3V LM2596S-3.3.5 (~ON/OFF), U2 5V LM2596S-5.3 (GND), U2 5V LM2596S-5.5 (~ON/OFF)
unnamed: D1.1 (K), L1.1, U2 5V LM2596S-5.2 (OUT)
unnamed: Barrel IN.A, D2.2 (A)
unnamed: D3.1 (K), L2 47 uH.1, U1 3.3V LM2596S-3.3.2 (OUT)
Vout_3.3V: C4.1, J6.1, L2 47 uH.2, U1 3.3V LM2596S-3.3.4 (FB)
Vout_5V: C1.1, J4.1, L1.2, U2 5V LM2596S-5.4 (FB)
Vout_12V: C2.1, C3.1, D2.1 (K), J3.1, U1 3.3V LM2596S-3.3.1 (VIN), U2 5V LM2596S-5.1 (VIN)

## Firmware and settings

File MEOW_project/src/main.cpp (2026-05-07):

#include "config.h"
#include "network.h"
#include "database.h"
#include "rfid.h"
#include "scales.h"
#include "website.h"

SPIClass sd_spi = SPIClass(VSPI);
HardwareSerial rfid_serial(2);

// debug for viewing an entry
inline void print_entry(Entry entry) {
	Serial.printf(
		"[FOOD: %7.2fg] "
		"[PLATFORM: %7.2fg] "
		"[RFID: %010u] "
		"= [ID: %03u] "
		"@ %s",
		entry.food_weight,
		entry.platform_weight,
		entry.rfid,
		entry.assumed_cat_id,
		entry.time == 0 ? "UNKNOWN\n" : ctime((time_t*)&entry.time)
	);
}

void setup() {
	if (DEBUG_MODE) Serial.begin(115200);
	if (DEBUG_MODE) Serial.println("Setup begin...");
	delay(1000); // delay for safety

	// init with pins
	sd_spi.begin(PIN_SD_SCK, PIN_SD_MISO, PIN_SD_MOSI, PIN_SD_CS);
	rfid_serial.begin(9600, SERIAL_8N1, PIN_RFID_RX, PIN_RFID_TX);
	scale_food.begin(PIN_SCALE_FOOD_DOUT, PIN_SCALE_FOOD_SCK);
	scale_platform.begin(PIN_SCALE_PLATFORM_DOUT, PIN_SCALE_PLATFORM_SCK);

	// setup motor
	pinMode(PIN_MOTOR_DIR,  OUTPUT);
	pinMode(PIN_MOTOR_STEP, OUTPUT);
	digitalWrite(PIN_MOTOR_DIR,  HIGH);
	digitalWrite(PIN_MOTOR_STEP, LOW);

	// scale setup
	scale_food.set_scale(CALIBRATION_FOOD);
	scale_platform.set_scale(CALIBRATION_PLATFORM);
	tare_scales();

	// connect network
	if (connect_wifi()) {
		sync_time();
		MDNS.begin(MDNS_NAME);
	}

	// website init
	setup_website();

	// connect database
	connect_db(sd_spi, PIN_SD_CS);

	if (DEBUG_MODE) Serial.println("Setup end.");
}

void loop() {
	// connect with wifi
	static unsigned long last_wifi_attempt = 0;
	constexpr unsigned long INTERVAL_WIFI_ATTEMPT = 10000; // 10s interval
	if (!is_wifi_connected() && millis() - last_wifi_attempt > INTERVAL_WIFI_ATTEMPT) {
		last_wifi_attempt = millis();
		connect_wifi();
		if (is_wifi_connected()) MDNS.begin(MDNS_NAME);
	}

	// sync time
	static unsigned long last_time_attempt = 0;
	constexpr unsigned long INTERVAL_TIME_ATTEMPT = 10000; // 10s interval
	if (!is_time_synced() && is_wifi_connected() && millis() - last_time_attempt > INTERVAL_TIME_ATTEMPT) {
		last_time_attempt = millis();
		sync_time();
	}

	// connect database
	static unsigned long last_db_attempt = 0;
	constexpr unsigned long INTERVAL_DB_ATTEMPT = 10000; // 10s interval
	if (!is_db_connected() && millis() - last_db_attempt > INTERVAL_DB_ATTEMPT) {
		last_db_attempt = millis();
		connect_db(sd_spi, PIN_SD_CS);
	}

	// updates scale readings
	tick_scales();

	// handle scheduled feedings
	handle_schedules();

	// gather current data
	static Entry current_entry;
	current_entry.rfid = get_rfid(rfid_serial);
	current_entry.food_weight = get_food_weight();
	current_entry.platform_weight = get_platform_weight();

	// select the best data from the current entries
	static Entry best_representation = {0};
	static float food_range = std::numeric_limits<float>::infinity();
	static float platform_range = std::numeric_limits<float>::infinity();
	if (current_entry.rfid != 0) best_representation.rfid = current_entry.rfid;

	constexpr float STABILITY_THRESHOLD_FOOD = 0.5;
	float new_food_range = get_food_stability();
	if (new_food_range <= STABILITY_THRESHOLD_FOOD) {
		// stable, keep lightest or newer if prev was unstable
		if (food_range > STABILITY_THRESHOLD_FOOD || current_entry.food_weight < best_representation.food_weight) {
			food_range = new_food_range;
			best_representation.food_weight = current_entry.food_weight;
		}
	} else if (new_food_range <= food_range) {
		// unstable, use the most stable
		food_range = new_food_range;
		best_representation.food_weight = current_entry.food_weight;
	}

	constexpr float STABILITY_THRESHOLD_PLATFORM = 0.5;
	float new_platform_range = get_platform_stability();
	if (new_platform_range <= STABILITY_THRESHOLD_PLATFORM) {
		// stable, keep heaviest or newer if prev was unstable
		if (platform_range > STABILITY_THRESHOLD_PLATFORM || current_entry.platform_weight > best_representation.platform_weight) {
			platform_range = new_platform_range;
			best_representation.platform_weight = current_entry.platform_weight;
		}
	} else if (new_platform_range <= platform_range) {
		// unstable, use the most stable
		platform_range = new_platform_range;
		best_representation.platform_weight = current_entry.platform_weight;
	}

	// keep track if it's okay to use the previous rfid scan
	static bool rfid_scanned_this_session = false;
	if (current_entry.platform_weight == 0) rfid_scanned_this_session = false;

	// push best representation to the db every second
	static unsigned long last_push = 0;
	constexpr unsigned long INTERVAL_PUSH = 1000; // 1s interval
	if (is_time_synced() && millis() - last_push > INTERVAL_PUSH) {
		last_push = millis();
		best_representation.time = get_time();

		// determine the cat if on platform
		static uint32_t active_cat = 0;
		if (best_representation.platform_weight != 0) {
			if (best_representation.rfid != 0) {
				rfid_scanned_this_session = true;
				active_cat = map_rfid_to_cat(best_representation.rfid);
			} else {
				if (!rfid_scanned_this_session) {
					active_cat = map_weight_to_cat(best_representation.platform_weight);
				}
			}
			best_representation.assumed_cat_id = active_cat;
			if (best_representation.rfid != 0) lastRfidTag = best_representation.rfid;
		} else {
			best_representation.assumed_cat_id = 0;
		}

		// always push entry to db (food weight logged even without cat)
		if (is_db_connected()) {
			if (DEBUG_MODE) print_entry(best_representation);
			push_entry(best_representation);
		}

		// reset best rep
		best_representation = {0};
		food_range = std::numeric_limits<float>::infinity();
		platform_range = std::numeric_limits<float>::infinity();
	}

	// keep web server alive
	server.handleClient();
}

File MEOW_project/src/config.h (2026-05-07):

#pragma once
#include <stdint.h>

#define DEBUG_MODE true

// sd card
constexpr int PIN_SD_CS = 13;
constexpr int PIN_SD_MOSI = 14;
constexpr int PIN_SD_MISO = 33;
constexpr int PIN_SD_SCK = 27;

// rfid
constexpr int PIN_RFID_RX = 32;
constexpr int PIN_RFID_TX = 26;

// scales
constexpr int PIN_SCALE_FOOD_DOUT = 23;
constexpr int PIN_SCALE_FOOD_SCK = 22;
constexpr int PIN_SCALE_PLATFORM_DOUT = 19;
constexpr int PIN_SCALE_PLATFORM_SCK = 18;

constexpr float CALIBRATION_FOOD = -1043.97115385; // TODO
constexpr float CALIBRATION_PLATFORM = -23.9055944056; // TODO

// motors
constexpr int PIN_MOTOR_DIR  = 25;
constexpr int PIN_MOTOR_STEP = 26;

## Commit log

2025-11-26 Revise README for M.E.O.W. project details
    Updated the README to provide detailed project information for M.E.O.W., an automated pet feeder with integrated weight tracking. Included sections on project status, system architecture, subsystem d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
2025-12-05 added storage block kicad files and test code
    [storage_block-B_Cu.gbl, storage_block-B_Mask.gbs, storage_block-B_Paste.gbp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]
2025-12-07 Revise README for Power Block clarity and detail
    Updated the README to provide a clearer overview of the Power Block's functionality and design, including details on power conversion, rail specifications, and validation processes.
2026-01-31 Added A system intergration schematic
    [MEOW_Power_Distribution_V2.kicad_pcb, MEOW_System_Integration.kicad_pcb, MEOW_System_Integration.kicad_sch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]
2026-02-17 Added Physical Enclsoure files
    [EncAugerV1.stl, EncBotV1.stl, EncBowlV1.stl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]
2026-02-18 simple sensor block kicad
    [sensor_block.kicad_pcb, sensor_block.kicad_sch]
2026-04-03 current status PCB ordered
    [MEOW_System_Integration-B_Cu.gbr, MEOW_System_Integration-B_Mask.gbr, MEOW_System_Integration-B_Paste.gbr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]
2026-05-07 updated cad stuff
    [MEOW_System_Integration.kicad_sch]
